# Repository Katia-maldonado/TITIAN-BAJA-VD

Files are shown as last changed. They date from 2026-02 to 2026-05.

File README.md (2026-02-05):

# Baja SAE – Titan Racing Baja
At **CSUF**, our Baja SAE team consists of 14 members, and our goal is to compete in the BAJA SAE Competion that is in Washougal, Washington in May 2026. We are divided into four subteams:

- Chassis / Ergonomics 
- Drivetrain  
- Suspension  
- Vehicle Dynamics / Data Acquisition  

---

## Vehicle Dynamics & Data Acquisition
For the **Vehicle Dynamics / Data Acquisition (VD/DAQ)** subteam, this focuses heavily on the electrical, sensor data, and data analysis work on the car.

We currently run **8 sensors** on the Baja car, all connected to an Arduino based DAQ system to record performance data during testing and competition runs. The system logs:

- Vehicle speed  
- Distance traveled  
- Time  
- Engine RPM  
- Secondary (CVT) RPM  
- Gyroscope data (roll, pitch, yaw)  
- 3-axis acceleration  
- Brake pressure bias  

All sensor data is routed through an **Arduino and SD card reader shield**, allowing each run to be logged directly to an SD card. The recorded data is then processed and analyzed in **MATLAB** to evaluate vehicle performance, CVT behavior, braking balance, and driver inputs.

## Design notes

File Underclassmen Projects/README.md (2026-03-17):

## Coding

I have a few underclassmen projects for anyone interested in writing code for **CVT tuning** and the **main DAQ harness** that will be installed on the car. These projects are a great opportunity to gain hands on experience with Arduino based data acquisition and sensor integration.

For coding related work, please reference **version 8 (v8)** of the code located in the **DAQ** or **version 9 (v9)** in the **CVT** folders. This version should be used as the baseline for development.

If you’re interested, **reach out to Katia on Discord**, and she can answer any questions you may have and help you get started.

---

### CVT DYNO

- [x] Add code to output **live data** onto a screen  
- [x] Display outputs for:
  - [x] Hall effect sensor (Primary RPM)  
  - [x] Hall effect sensor (Secondary RPM)  
  - [x] Hall effect sensor (Disk Brake RPM)  

---

### DAQ (On Vehicle)

- [x] Code the **IMU (MPU-6050)** to record and send its data to the Arduino  
- [x] Log IMU data onto an SD card using the **SD Card Reader Shield** (so it can be exported to Excel / MATLAB later)  
- [x] IMU signals to record:
  - [x] Angular velocity (gyro): **X, Y, Z**
  - [x] Linear acceleration (accelerometer): **X, Y, Z**

> Note: The MPU-6050 is a 3-axis accelerometer and gyroscope. There are many examples available on GitHub and YouTube that can be used as references.

---

### Driver Dash Display

We are also exploring the addition of a **driver dash display** to provide live feedback during vehicle operation. The goal is to give the driver real time readings without relying on post run data analysis.

Planned display outputs include:
- Vehicle speed  
- Secondary RPM  
- CVT belt temperature (IR sensor)  

Due to the off road environment, the display must be **IP67-rated** to withstand dust, water, mud, and vibration. Many off the shelf IP67 displays are expensive, so part of this project is to find **cost effective display solutions** that can meet durability requirements.

This project may include:
- Researching low cost display options compatible with Arduino  
- Designing or selecting a **waterproof enclosure** for the screen  
- Integrating the display with the existing DAQ system  
- Ensuring readability in outdoor and high vibration conditions  

------

## CAD Fixes & Required Updates

The following items outline **specific fixes and updates** that need to be made to the existing CAD drawings for both the **CVT** and **DAQ** electrical harnesses. These updates are necessary to keep the CAD aligned with the actual electrical design and wiring standards.

---

#### CVT Harness CAD (DWG) Fixes

- Fix the electrical connections between the **battery, fuse, buck converter, and GND bus bar**
- Standardize **connector naming**:
  - All identical connectors (ex: all **JST-VH** connectors) should share the same label  
    - Example: all JST-VH connectors labeled as **C3**
- Add a **Quantity** column to the connector table
  - This applies to all repeating connectors
- Rename **BPS** to:
  - **Hall Effect – Brake Wheel RPM**

---

#### DAQ Harness CAD (DWG) Fixes

- Standardize **connector labeling**, following the same rules as the CVT harness
- Add a **Quantity** column to the connector table
- Fix electrical connections between the **battery, fuse, buck converter, and GND bus bar**
- Correct wiring errors where wires were accidentally placed in unused bus bar locations
- Add a **12V bus bar** and move the following components from 5V to **12V**:

**12V Components**
- Spark plug tachometer  
- BPS 1  
- BPS 2  
- Brake switch and brake light (wired in series)  
- Arduino  

**5V Components**
- Hall effect sensor  
- CVT infrared (IR) sensor  
- XBee Xplorer shield  
- IMU  
- GPS  

**GND Connections**
- GPS  
- Push button  
- LED  
- RTC  
- Arduino  
- Spark plug tachometer  
- BPS 1  
- BPS 2  
- Hall effect sensor  
- CVT IR sensor  
- XBee  
- Brake light  
- IMU  
- Buck converter (IN)  
- Buck converter (OUT)  

- **Sheet 3 Fix**:
  - Trim the **GND wire connected to the QWIIC adapter**
  - The wire is currently too long and should be shortened in the DWG

---

Maintaining accurate CAD drawings is critical for harness fabrication, troubleshooting, and future revisions. These fixes should be completed before final harness assembly.

## Sensors - Hands on testing

For those interested in hands on work, there are opportunities to help test and validate the sensors we are using by connecting them to an Arduino and breadboard while we wait for final parts to be delivered. This is a great way to get familiar with the hardware and basic wiring before full integration.

A future project will involve assisting with **harness assembly and integration** once all components arrive, including helping connect and route the wiring for the CVT dyno and on vehicle DAQ systems. Interested students should reach out to Katia for more information.

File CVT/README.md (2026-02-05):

## CVT Dyno Harness & Tuning Overview

In addition to the vehicle DAQ system, we are developing a **separate electrical harness for the CVT dyno**. This setup is designed specifically for **CVT testing and tuning** in a controlled environment and does not require the same level of durability as the on vehicle harness.

The CVT dyno harness uses an **Arduino Uno with an SD card reader shield** to log data and display real time feedback during testing. The system includes the following components:

- Hall effect sensor – Primary RPM  
- Hall effect sensor – Secondary RPM  
- Hall effect sensor – Disk Brake RPM  
- Push button (test control / reset)  
- LED indicators (system status)  
- Real Time Clock (RTC)  
- Display screen for real time output  

The hall effect sensors allow us to measure **primary, secondary, and wheel RPM**, which are critical for understanding CVT behavior under different load and throttle conditions. Data is logged to an SD card for analysis, while the display provides immediate feedback during testing.

---

## Purpose of CVT Tuning

The purpose of CVT tuning is to optimize the transmission’s performance by ensuring the engine operates within its ideal RPM range throughout acceleration and load changes. By analyzing the relationship between **primary RPM, secondary RPM, and wheel RPM**, we can evaluate:

- Shift behavior and ratio changes  
- Belt slip and engagement consistency  
- Backshift response under load  
- Overall drivetrain efficiency  

This data approach allows us to make informed adjustments to **spring rates, flyweights, and CVT setup** rather than relying solely on trial and error. The CVT dyno harness provides a repeatable testing environment that directly supports on vehicle performance improvements.

---

## To Do List

- [x] Hall effect sensor – Primary RPM  
- [x] Hall effect sensor – Secondary RPM  
- [ ] Hall effect sensor – Wheel RPM  
- [x] Push button (test control / reset)  
- [x] LED indicators (system status)  
- [x] Real-Time Clock (RTC)  
- [ ] Display screen for real-time output

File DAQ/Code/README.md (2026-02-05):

## Code Notes & Versioning

**Note:** **Version 8 (v8)** is the most current and stable version of the DAQ code. It has been tested using an **Arduino and breadboard** and should be used as the baseline for any new development.

All new code files must follow the updated naming convention:

Example:
- `v9_DAQ_KM`

---

## Required Code Header Comment

Each DAQ code file must include a **comment block at the very top** of the file describing what the code does and which sensors are used. This helps keep the repository organized and makes code review easier.

### Required Format (Copy & Paste)

```cpp
/*
Version: v#
Author: Name
System: DAQ

Description:
- Brief description of what was added or changed

Sensors Included:
- List all sensors used in this code
*/

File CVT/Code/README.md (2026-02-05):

Note: Version 8 is the most current code and it was tested with an Arduino and Breadboard.

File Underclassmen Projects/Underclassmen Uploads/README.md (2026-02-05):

# Underclassmen Code Submissions

This folder is used for underclassmen to upload **code contributions** related to the **CVT dyno** and **on vehicle DAQ system**. To keep the repository organized and easy to review, please follow the naming and documentation rules below.

---

## File Naming Convention

All uploaded code files must follow this format:

### Examples
- `v9_CVT_KatiaM`
- `v9_DAQ_KatiaM`

### Rules
- Use the current version number (ex: `v9`)
- Specify the system:
  - `CVT` for CVT dyno code
  - `DAQ` for on-vehicle DAQ code
- Use your **first name + last initial**
- Do not use spaces in file names

---

## Required Code Header Comment

Each code file **must include a comment block at the very top** describing what was changed and what sensors are used. This helps with review and future debugging.

### Required Format (Copy & Paste)

```
/*
Author: Your Name
Version: version number (ex:v9)
System: CVT or DAQ

Description:
- Briefly describe what you added or modified in this version

Sensors Included:
- List all sensors used in this code
*/
/*
Author: Katia Maldonado
Version: v9
System: CVT

Description:
- Added live screen output for RPM values
- Improved hall effect sensor debounce

Sensors Included:
- Hall effect sensor (Primary RPM)
- Hall effect sensor (Secondary RPM)
- Hall effect sensor (Wheel RPM)
*/

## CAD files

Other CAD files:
CVT/CAD/v3/CVT_DYNO_V3_BOM_WIRE_CONNECTO_KM.dwg
DAQ/CAD/v6/DAQ_Harness_V6_KM.dwg
DAQ/CAD/v6/DAQ_CONNECTOR_V6_KM.dwg
DAQ/CAD/v6/DAQ_WIRE_V6_KM.dwg
DAQ/CAD/v6/DAQ_Live_Transmission_V6_KM.dwg
DAQ/CAD/v6/DAQ_IMU_ARDUINO_BOX_V6_KM.dwg
DAQ/CAD/v6/DAQ_BOM_V6_KM.dwg
CVT/CAD/v1/CVT_DYNO_V1_KM.dwg
CVT/CAD/v2/CVT_DYNO_V2_KM.dwg
DAQ/CAD/v3/DAQ_Harness_Circuit.dwg
DAQ/CAD/v4/DAQ_V1_KM.dwg
DAQ/CAD/v5/DAQ_Live_Transmission_V1_KM.dwg
CVT/CAD/v2/CVT_DYNO_V2_KM (1).dwg
DAQ/CAD/v4/Live_Transmission_V1_KM.dwg
DAQ/CAD/v5/DAQ_Harness_V1_KM.dwg
DAQ/CAD/v5/DAQ_BOM_V1_KM.dwg
DAQ/CAD/v5/DAQ_IMU_RTC_V1_KM.dwg
DAQ/CAD/v5/DAQ_WIRE_V1_KM.dwg
DAQ/CAD/v5/DAQ_CONNECTOR_V1_KM.dwg

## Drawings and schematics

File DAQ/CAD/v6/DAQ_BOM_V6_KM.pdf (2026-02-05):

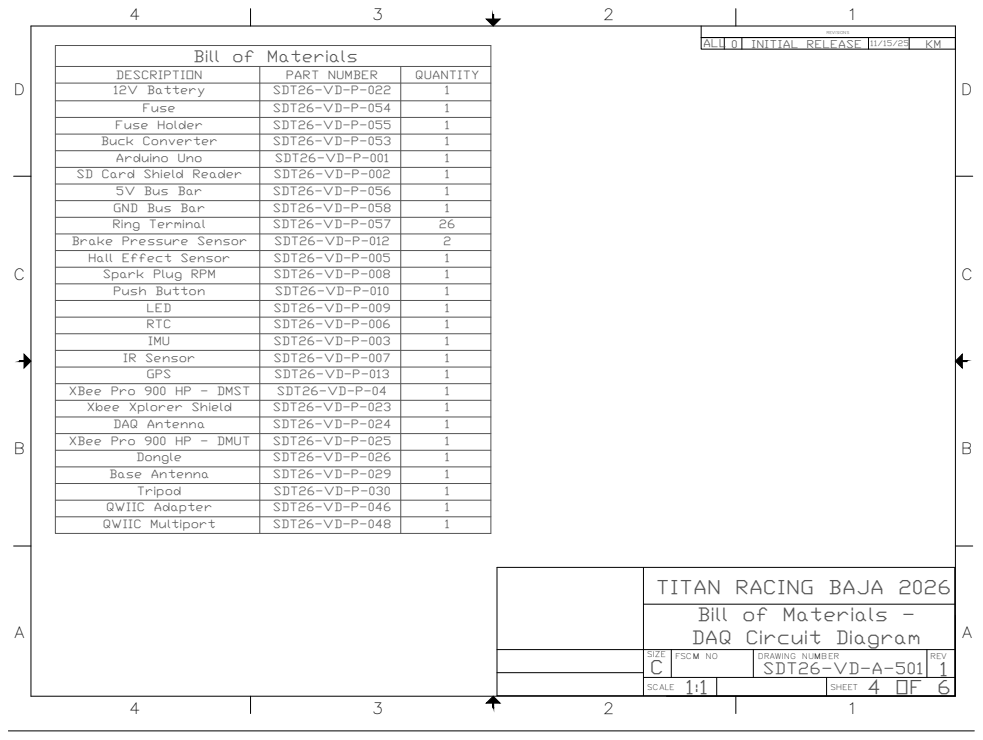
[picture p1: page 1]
D 1 REVISIONS; SIZE; FSCM NO; DRAWING NUMBER; REV SCALE; SHEET Bill of Materials - DAQ Circuit Diagram C; 4 OF 61 ALL 0; INITIAL RELEASE; KM TITAN RACING BAJA 2026 SDT26-VD-A-501 Bill of Materials DESCRIPTION; PART NUMBER; QUANTITY 12V Battery; SDT26-VD-P-022; 1 Fuse; SDT26-VD-P-054; 1 Fuse Holder; SDT26-VD-P-055; 1 Buck Converter; SDT26-VD-P-053; 1 Arduino Uno; SDT26-VD-P-001; 1 SD Card Shield Reader; SDT26-VD-P-002; 1 5V Bus Bar; SDT26-VD-P-056; 1 GND Bus Bar; SDT26-VD-P-058; 1 Ring Terminal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

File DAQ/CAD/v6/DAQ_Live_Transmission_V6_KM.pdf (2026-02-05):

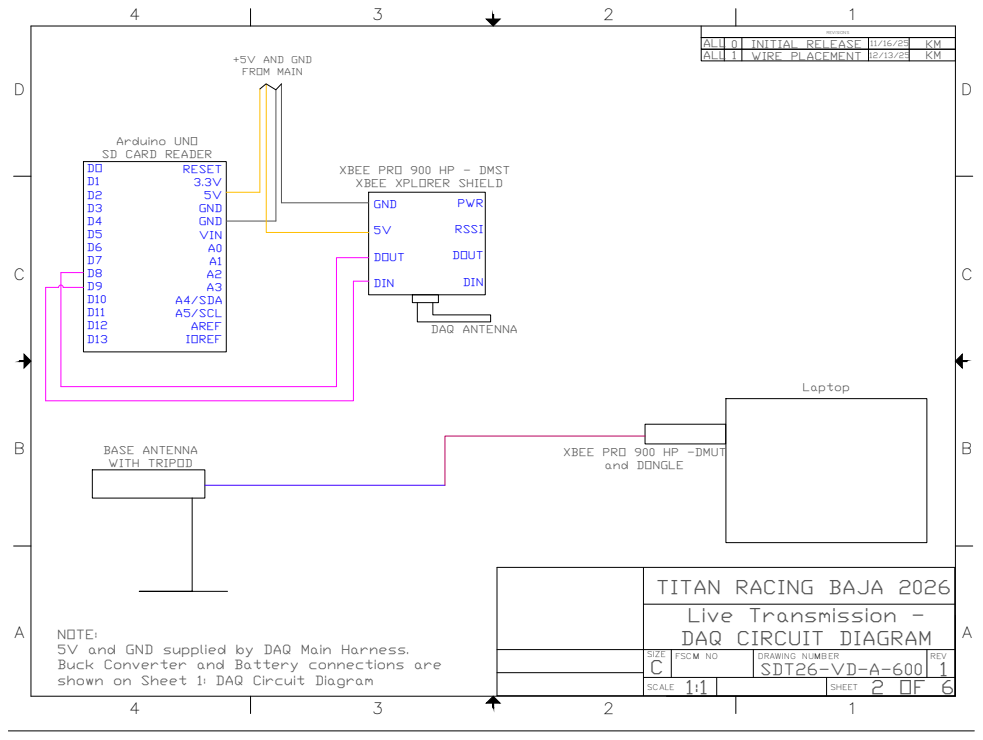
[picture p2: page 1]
D 1 REVISIONS; SIZE; FSCM NO; DRAWING NUMBER; REV SCALE; SHEET Live Transmission - DAQ CIRCUIT DIAGRAM C; 2 OF 61 ALL 0; INITIAL RELEASE; KM TITAN RACING BAJA 2026 SDT26-VD-A-600 DOD1 D2D3D4D5D6D7D8D9D10 D11 D12 D13; RESET 3.3V5V GND GND VINA0A1 A2A3 A4/SDA A5/SCL AREF IOREF Arduino UNO SD CARD READER; +5V AND GND FROM MAIN NOTE: 5V and GND supplied by DAQ Main Harness. Buck Converter and Battery connections are shown on Sheet 1: DAQ Circuit DiagramGND 5VDOUT DIN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

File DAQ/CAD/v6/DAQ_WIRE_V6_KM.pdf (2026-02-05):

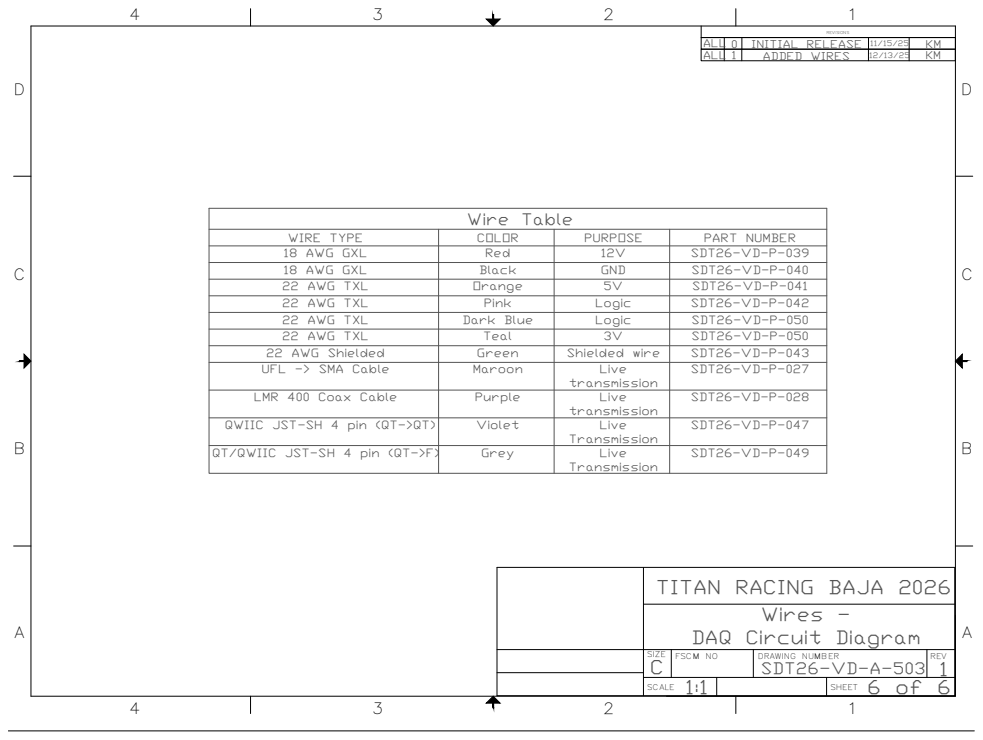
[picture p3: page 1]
D 1 REVISIONS; SIZE; FSCM NO; DRAWING NUMBER; REV SCALE; SHEET Wires - DAQ Circuit Diagram C; 6 of 61 ALL 0; INITIAL RELEASE; KM TITAN RACING BAJA 2026 SDT26-VD-A-503 Wire Table WIRE TYPE; COLOR; PURPOSE; PART NUMBER 18 AWG GXL; Red; SDT26-VD-P-039 18 AWG GXL; Black; GND; SDT26-VD-P-040 22 AWG TXL; Orange; SDT26-VD-P-041 22 AWG TXL; Pink; Logic; SDT26-VD-P-042 22 AWG TXL; Dark Blue; SDT26-VD-P-050 22 AWG TXL; Teal; SDT26-VD-P-050 22 AWG Shielded; Green; Shielded wire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

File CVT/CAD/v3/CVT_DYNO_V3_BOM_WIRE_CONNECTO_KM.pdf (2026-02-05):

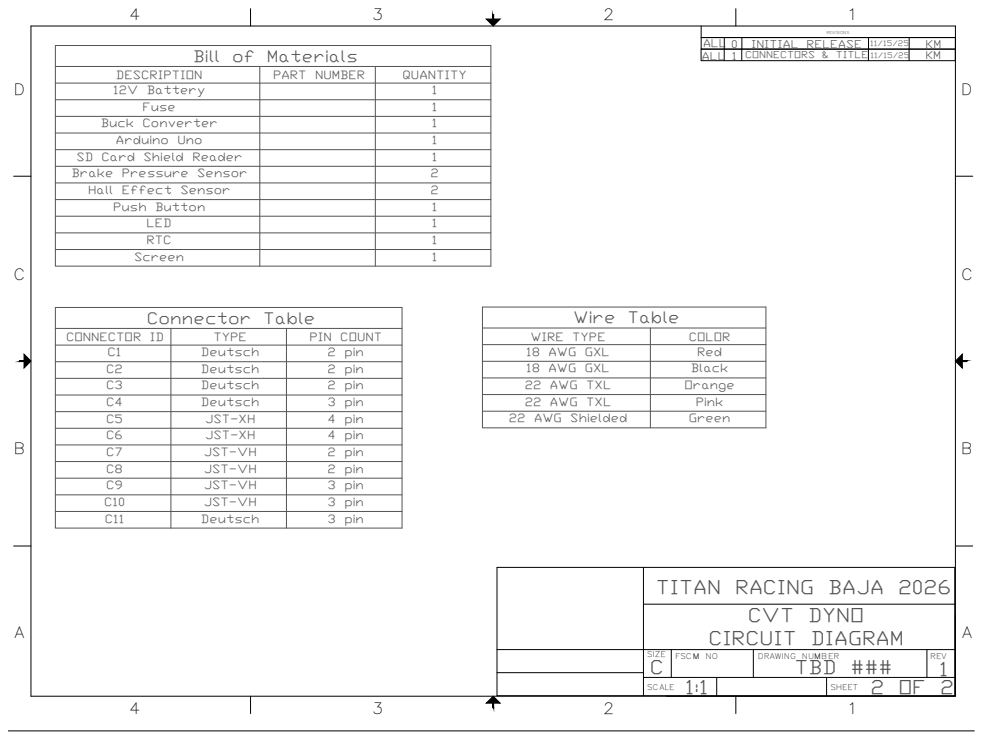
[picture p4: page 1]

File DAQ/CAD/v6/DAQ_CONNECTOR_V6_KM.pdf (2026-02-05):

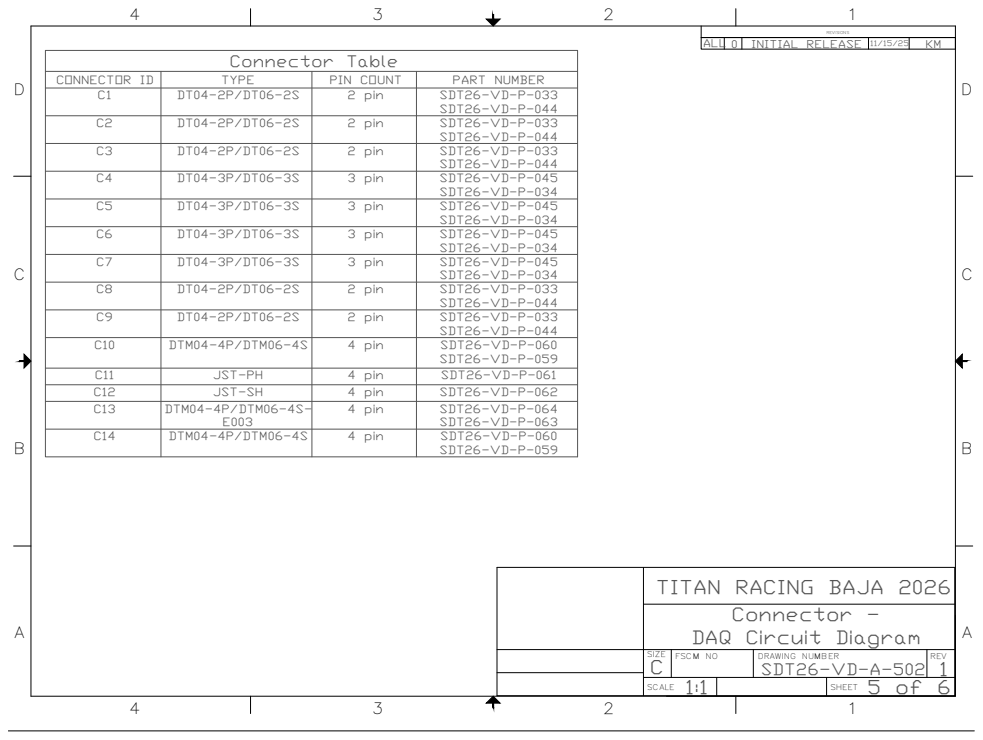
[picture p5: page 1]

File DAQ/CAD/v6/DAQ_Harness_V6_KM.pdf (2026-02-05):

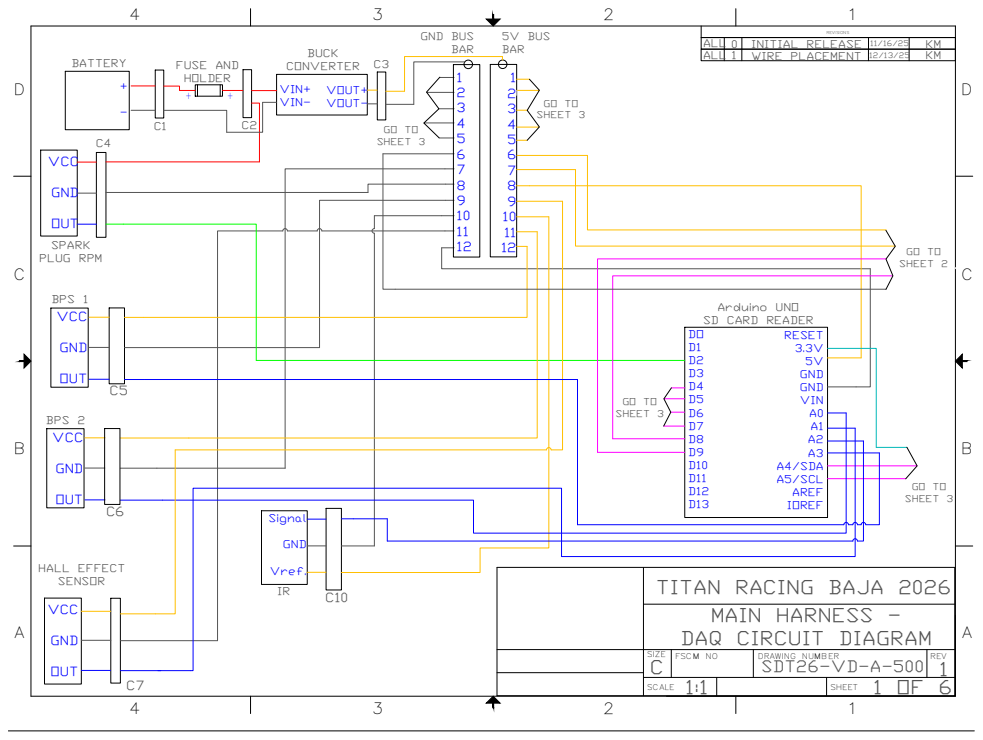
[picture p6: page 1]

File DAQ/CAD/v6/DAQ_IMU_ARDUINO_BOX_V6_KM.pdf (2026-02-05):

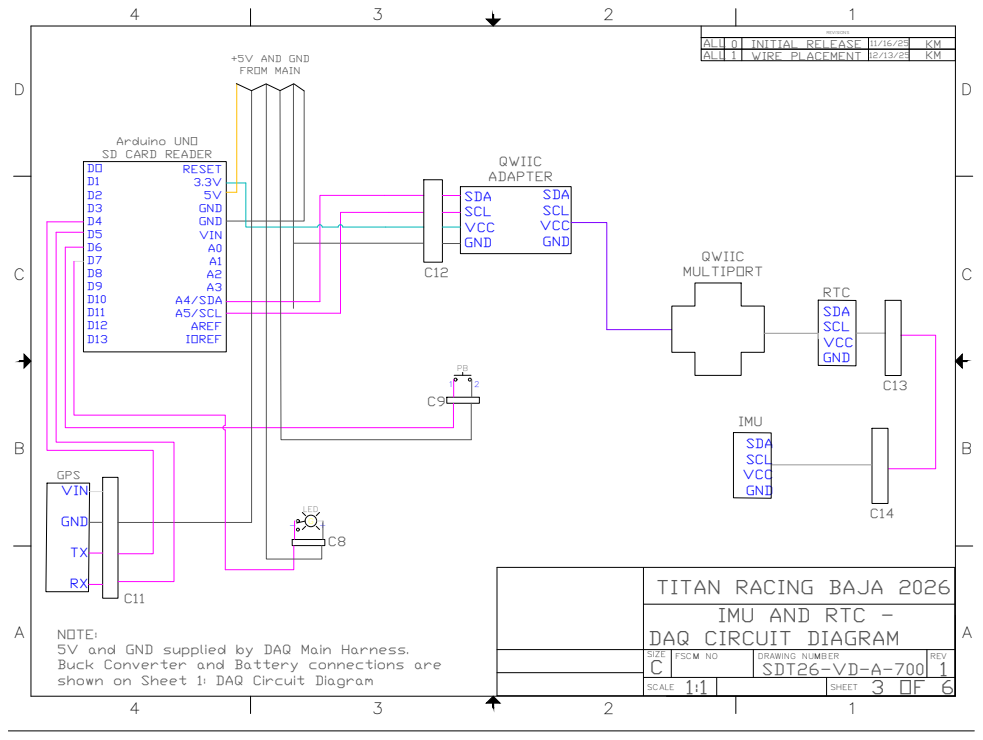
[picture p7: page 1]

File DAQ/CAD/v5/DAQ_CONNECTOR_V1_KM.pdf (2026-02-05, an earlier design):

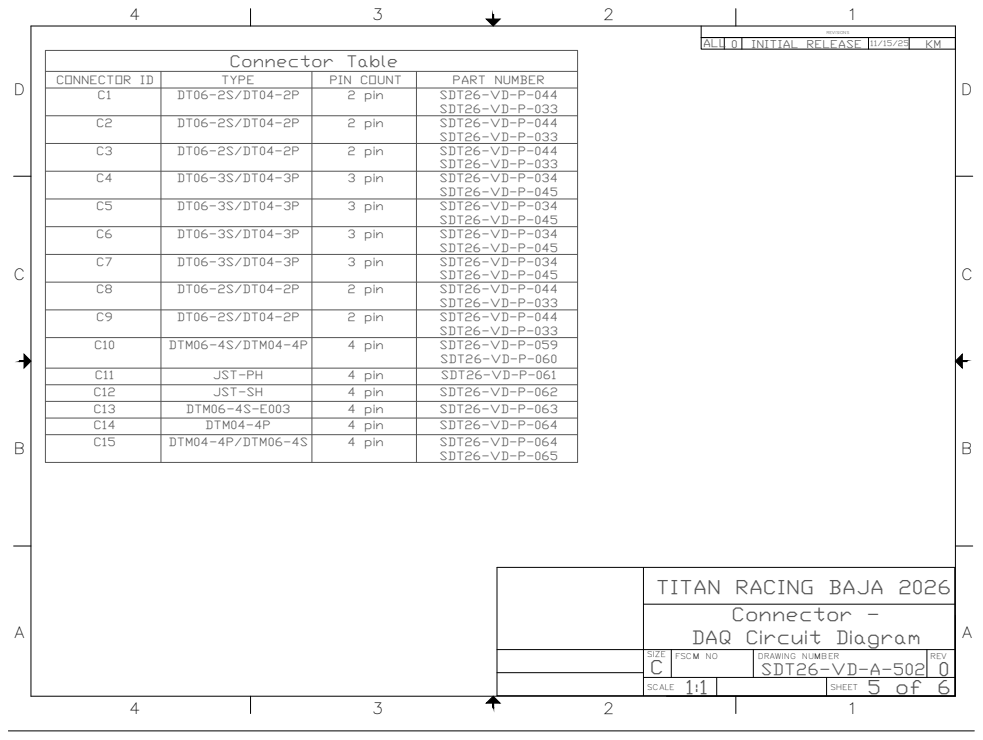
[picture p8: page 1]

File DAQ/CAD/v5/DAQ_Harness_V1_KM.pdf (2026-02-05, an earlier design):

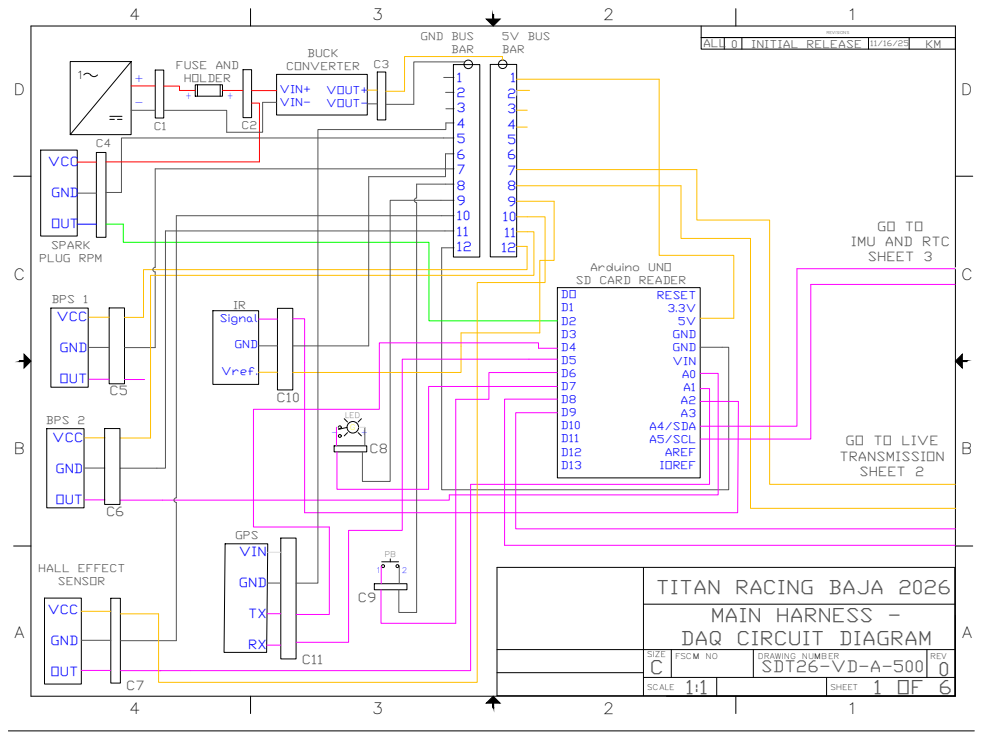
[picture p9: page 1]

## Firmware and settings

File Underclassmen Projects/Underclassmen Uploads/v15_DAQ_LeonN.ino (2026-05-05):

/*
Version: v15
Author: Leon Nguyen
System: DAQ

Description:
- Retained GPS PPS hardware interrupt for silent background tracking, but omitted data from CSV for clean Excel logs [UPDATED]
- Updated IMU software axis mapping to match new physical orientation (X=Up, Y=Left, Z=Rear) [UPDATED]
- Removed DS3231 RTC module dependencies, and shifted entirely to Teensy 4.1 internal hardware RTC (VBAT ON) for zero-latency timestamping [NEW]
- Removed SQW Interrupt hardware sync and Enclosure Temperature tracking [UPDATED]
- Remapped hardware pins across the board, GPS moved to Serial8, XBee moved to Serial5 [UPDATED] 
- IMU address restored to default 0x68 (AD0 pulled low/floating) since it is now the sole device on the bus [UPDATED]
= Removed DIVIDER_MULTIPLIER math for CVT readings [UPDATED]

Sensors Included:
- Spark Plug RPM Adapter (Primary RPM)
- Hall Effect Sensor (Secondary RPM)
- MPU-6050 (Accelerometer & Gyroscope - Interrupt Driven)
- Adafruit Ultimate GPS Module (NMEA 115200 baud, 10Hz, PPS)
- Brake Pressure Sensor (Analog Front)
- Brake Pressure Sensor (Analog Rear)
- CVT Belt Temp Sensor (Analog AiM)
- XBee-PRO 900HP (S3B) (Live-Telemetry Module)

TEENSY 4.1 HARDWARE WIRING GUIDE:
--- COMMUNICATION PINS ---
- IMU(SDA / SCL)         -> Pin 18 / Pin 19
- GPS RX (Serial8 RX8)   -> Pin 34
- GPS TX (Serial8 TX8)   -> Pin 35
- XBee RX (Serial5 RX5)  -> Pin 21
- XBee TX (Serial5 TX5)  -> Pin 20

--- ANALOG PINS ---
- Front Brake Pressure   -> Pin 40 (Shunt Resistor)
- Rear Brake Pressure    -> Pin 41 (Shunt Resistor)
- CVT Belt Temp (AiM IR) -> Pin 38 (5V to 3.3V Divider)

--- DIGITAL PINS ---
- Primary RPM (Spark)    -> Pin 37 (12V to 3.3V Divider)
- Secondary RPM (Hall)   -> Pin 36 (INTERNAL_PULLUP)
- LED Indicator          -> Pin 39 (MOSFET)
- Push Button            -> Pin 23 (INTERNAL_PULLUP)

--- AUXILIARY / SYNC PINS ---
- GPS PPS Pin            -> Pin 33 (Hardware Sync)
- IMU INT Pin            -> Pin 22 (Hardware Sync)
*/

#include <Wire.h>
#include <SPI.h>
#include <SD.h>
#include <TimeLib.h> 
#include <Adafruit_MPU6050.h>
#include <Adafruit_Sensor.h>
#include <TinyGPS++.h>
#include <Watchdog_t4.h>

Adafruit_MPU6050 mpu;
TinyGPSPlus gps;
WDT_T4<WDT1> wdt;

// -------- Pins -------- 
const int pinRPM_Primary   = 37;
const int pinRPM_Secondary = 36;
const int ledPin           = 39;
const int buttonPin        = 23;
const int pinBrakeF        = 40;
const int pinBrakeR        = 41;
const int pinCVT           = 38;
const int pinGPS_PPS       = 33;
const int pinIMU_INT       = 22;

// -------- Settings --------
const unsigned long SAMPLE_MS     = 50;
const uint8_t       PPR           = 2;
const unsigned long DEBOUNCE_MS   = 50; 
const unsigned long RPM_DEBOUNCE  = 2000;

// --- Ring Buffer Settings ---
const int BUFFER_SIZE = 100;
char logBuffer[BUFFER_SIZE][256];
volatile int head = 0;
volatile int tail = 0;
volatile int xbeeTail = 0;

const float DIVIDER_MULTIPLIER = 2.0;
const float MINUTE_MICROS_PPR = 60000000.0 / PPR;

// -------- Counters / State --------
volatile unsigned long lastTimeP = 0;
volatile unsigned long periodP = 0;  

volatile unsigned long lastTimeS = 0;
volatile unsigned long periodS = 0;

volatile unsigned long lastPPSMicros = 0; 
volatile unsigned long ppsDelta = 0; // Tracks microsecond drift

bool logging      = false;
bool lastStable   = HIGH;
bool debouncing   = false;
unsigned long tDebounce = 0;

bool sdOk = false, mpuOk = false;
unsigned long t0_ms = 0; 
char filename[32]; 

File logFile;

// -------- Sensor Data Globals --------
float carAccX = 0, carAccY = 0, carAccZ = 0;
float carGyroX = 0, carGyroY = 0, carGyroZ = 0;

// --- Time Sync Helper Function ---
time_t getTeensy3Time() {
  return Teensy3Clock.get();
}

// --- FASTRUN ISRs (Loaded into ITCM RAM for zero latency) ---
void FASTRUN isrP() { 
  unsigned long now = micros();
  if (now - lastTimeP > RPM_DEBOUNCE) {
    periodP = now - lastTimeP;
    lastTimeP = now;
  }
}

void FASTRUN isrS() { 
  unsigned long now = micros();
  if (now - lastTimeS > 1000) {
    periodS = now - lastTimeS;
    lastTimeS = now;
  }
}

void FASTRUN isrPPS() { 
  unsigned long now = micros();
  ppsDelta = now - lastPPSMicros; // Calculate exact drift
  lastPPSMicros = now; 
}

// -----------------------------------------------------------

void updateGPS() {
  while (Serial8.available() > 0) gps.encode(Serial8.read());
}

void buildNewRunFilename() {
  int run = 1;
  do {
    sprintf(filename, "RUN%03d.CSV", run);
    run++;
  } while (SD.exists(filename));
}

void writeHeader() {
  // PPS columns intentionally omitted to keep CSV clean
  logFile.println(F("Date,Time,P_RPM,S_RPM,AccX,AccY,AccZ,GyroX,GyroY,GyroZ,Lat,Lon,Speed_MPH,BrakeF_PSI,BrakeR_PSI,CVT_TempC"));
  logFile.flush();
  Serial.println(F("Header written"));
}

float readPressurePSI(int pin) {
  int val = analogRead(pin);
  // OPTIMIZED: 12-bit ADC resolution
  float pinVoltage = (val / 4095.0) * 3.3;
  // Calculate raw PSI based on the theoretical 0.60V baseline
  float psi = ((pinVoltage - 0.6) / 2.4) * 2000.0;
  return psi;
}

float readTempC(int pin) {
  // 1. Read the raw 12-bit hardware value (0 to 4095)
  int raw = analogRead(pin);
  
  // 2. Create 'pinV' and calculates the voltage
  float pinV = raw * (3.3 / 4095.0); 
  
  // 3. Now the compiler knows what pinV is
  float sensorV = pinV; 
  
  // 4. Safety check (sensor baseline is 820mV at -20C)
  if (sensorV < 0.8) return -20.0;
  
  // 5. Calculate temp based on the 131.07 °C/V slope
  return (sensorV - 0.82) * 131.07 - 20.0;
}

// --- Custom I2C Burst Read for MPU-6050 ---
void readIMUBurst() {
  Wire.beginTransmission(0x68); // 0x68 is the default MPU address
  Wire.write(0x3B); 
  Wire.endTransmission(false);  // 'false' keeps the I2C connection open/active

  Wire.requestFrom((uint8_t)0x68, (uint8_t)14);
  if (Wire.available() == 14) {
    int16_t rawAccX = Wire.read() << 8 | Wire.read();
    int16_t rawAccY = Wire.read() << 8 | Wire.read();
    int16_t rawAccZ = Wire.read() << 8 | Wire.read();
    int16_t rawTemp = Wire.read() << 8 | Wire.read();
    int16_t rawGyroX = Wire.read() << 8 | Wire.read();
    int16_t rawGyroY = Wire.read() << 8 | Wire.read();
    int16_t rawGyroZ = Wire.read() << 8 | Wire.read();
    
    // --- ORIENTATION MAPPING ---
    // (X points UP, Y points LEFT, Z points REAR)
    // ACCELEROMETER
    carAccX = -(rawAccZ / 4096.0); // Car Forward/Braking (Z is Rear -> Forward is -Z)
    carAccY = -(rawAccY / 4096.0); // Car Cornering Right (Y is Left -> Right is -Y)
    carAccZ =  (rawAccX / 4096.0); // Car Jumps/Vertical Up (X is Up -> Up is +X)
    
    // GYROSCOPE (Right-Hand Rule matched to axes)
    carGyroX = -(rawGyroZ / 65.5); // Roll (Rotation around Forward axis)
    carGyroY = -(rawGyroY / 65.5); // Pitch (Rotation around Right axis)
    carGyroZ =  (rawGyroX / 65.5); // Yaw (Rotation around Up axis)
  }
}

void setup() {
  Serial.begin(9600);
  Wire.begin();
  Wire.setClock(400000);
  Wire.setTimeout(10000);

  static char gpsBuffer[256];
  Serial8.addMemoryForRead(gpsBuffer, sizeof(gpsBuffer));
  static char xbeeBuffer[1024];
  Serial5.addMemoryForWrite(xbeeBuffer, sizeof(xbeeBuffer)); 

  Serial5.begin(115200); 
  
  delay(1000);
  Serial8.begin(9600);
  Serial8.println(F("$PMTK251,115200*1F"));
  delay(100);
  Serial8.begin(115200);
  // "NMEA Diet": Configured to output strictly RMC sentences for reduced CPU load
  Serial8.println(F("$PMTK314,0,1,0,0,0,0,0,0,0,0,0,0,0,0,0,0,0,0,0*29"));
  delay(100);
  Serial8.println(F("$PMTK220,100*2F"));

  pinMode(ledPin, OUTPUT);
  digitalWriteFast(ledPin, LOW);
  pinMode(buttonPin, INPUT_PULLUP);
  pinMode(pinRPM_Primary, INPUT);
  pinMode(pinRPM_Secondary, INPUT_PULLUP);

  pinMode(pinIMU_INT, INPUT); 
  pinMode(pinGPS_PPS, INPUT);
  
  // 12-bit ADC for higher analog sensitivity
  analogReadResolution(12);
  analogReadAveraging(16);

  attachInterrupt(digitalPinToInterrupt(pinRPM_Primary), isrP, RISING);
  attachInterrupt(digitalPinToInterrupt(pinRPM_Secondary), isrS, FALLING);
  attachInterrupt(digitalPinToInterrupt(pinGPS_PPS), isrPPS, RISING);

  wdt.feed();
  sdOk = SD.begin(BUILTIN_SDCARD);

  // --- Teensy Internal RTC Setup ---
  setSyncProvider(getTeensy3Time);
  if (timeStatus() != timeSet) {
    Serial.println(F("Unable to sync with the Teensy RTC"));
  } else {
    Serial.println(F("Teensy RTC has set the system time"));
  }

  // --- IMU Configuration ---
  if (!mpu.begin(0x68)) {
    mpuOk = false;
  } else {
    mpuOk = true;
    mpu.setAccelerometerRange(MPU6050_RANGE_8_G);
    mpu.setGyroRange(MPU6050_RANGE_500_DEG);
    mpu.setFilterBandwidth(MPU6050_BAND_21_HZ);
    
    Wire.beginTransmission(0x68);
    Wire.write(0x37); 
    Wire.write(0x10); 
    Wire.write(0x01); 
    Wire.endTransmission();
  }

  t0_ms = millis();
  WDT_timings_t config;
  config.trigger = 2;
  config.timeout = 3;
  wdt.begin(config);
}

void loop() {
  wdt.feed();
  unsigned long nowMs = millis();
  updateGPS();

  bool raw = digitalReadFast(buttonPin);
  if (!debouncing && raw != lastStable) {
    debouncing = true;
    tDebounce = nowMs;
  }
  
  if (debouncing && (nowMs - tDebounce) > DEBOUNCE_MS) {
    bool raw2 = digitalReadFast(buttonPin);
    if (raw2 != lastStable) {
      if (lastStable == LOW && raw2 == HIGH) {
        if (!logging) {
          wdt.feed();
          if (SD.begin(BUILTIN_SDCARD)) {
            buildNewRunFilename();
            logFile = SD.open(filename, FILE_WRITE);
            if (logFile) { writeHeader(); logging = true; digitalWriteFast(ledPin, HIGH); }
          }
        } else {
          logging = false;
          digitalWriteFast(ledPin, LOW);
          if (logFile) logFile.close();
        }
      }
      lastStable = raw2;
    }
    debouncing = false;
  }

  // --- Main 20Hz Sampling Loop ---
  static unsigned long lastSample = 0;
  if (logging && (nowMs - lastSample >= SAMPLE_MS)) {
    lastSample = nowMs;

    noInterrupts();
    unsigned long pP = periodP; unsigned long tP = lastTimeP;
    unsigned long pS = periodS; unsigned long tS = lastTimeS;
    
    // Track the PPS values in the background in case we need them later
    unsigned long ppsSync = lastPPSMicros; 
    unsigned long syncDelta = ppsDelta; 
    interrupts();
    
    if (mpuOk && digitalReadFast(pinIMU_INT) == HIGH) {
        readIMUBurst();
    }

    float rpmP = (pP > 0 && (micros() - tP < 500000)) ? MINUTE_MICROS_PPR / (float)pP : 0.0;
    float rpmS = (pS > 0 && (micros() - tS < 500000)) ? MINUTE_MICROS_PPR / (float)pS : 0.0;

    if (logFile) {
      static char dataLine[256]; static char timeStr[32];
      time_t t = Teensy3Clock.get(); 
      snprintf(timeStr, sizeof(timeStr), "%04d/%02d/%02d,%02d:%02d:%02d", 
               year(t), month(t), day(t), hour(t), minute(t), second(t));
               
      // Removed PPS values from the string to keep the CSV clean
      snprintf(dataLine, sizeof(dataLine), "%s,%.0f,%.0f,%.2f,%.2f,%.2f,%.2f,%.2f,%.2f,%.6f,%.6f,%.2f,%.0f,%.0f,%.1f", 
               timeStr, rpmP, rpmS, carAccX, carAccY, carAccZ, carGyroX, carGyroY, carGyroZ, gps.location.lat(), gps.location.lng(), gps.speed.mph(), readPressurePSI(pinBrakeF), readPressurePSI(pinBrakeR), readTempC(pinCVT));
               
      int nextHead = (head + 1) % BUFFER_SIZE;
      if (nextHead != tail && nextHead != xbeeTail) {
          strncpy(logBuffer[head], dataLine, 255);
          logBuffer[head][255] = '\0'; head = nextHead;
      } else {
          tail = (tail + 1) % BUFFER_SIZE;
          xbeeTail = (xbeeTail + 1) % BUFFER_SIZE;
          strncpy(logBuffer[head], dataLine, 255); logBuffer[head][255] = '\0'; head = nextHead;
      }
    }
  }
  
  if (!logging) {
      unsigned long blinkInterval = gps.location.isValid() ? 1000 : 200;
      if ((millis() % blinkInterval) < 50) digitalWriteFast(ledPin, HIGH); else digitalWriteFast(ledPin, LOW);
  }
  
  static unsigned long lastForceFlush = 0;
  if (logging && logFile) {
      if (head != tail) { logFile.println(logBuffer[tail]);
      tail = (tail + 1) % BUFFER_SIZE; }
      if (millis() - lastForceFlush > 2000) { logFile.flush();
      lastForceFlush = millis(); }
  }

  if (logging && (head != xbeeTail)) {
      Serial5.println(logBuffer[xbeeTail]);
      xbeeTail = (xbeeTail + 1) % BUFFER_SIZE;
  }
}

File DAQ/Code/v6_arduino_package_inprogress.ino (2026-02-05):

// CSUF BAJA SAE – VD/DAQ (Robust Version)
// Logs even if RTC or IMU init fails.
// Button D7<->GND toggles logging (INPUT_PULLUP). LED D8 ON while logging.
// SD CS=D10. Hall sensors on D2/D3. RTC & IMU share A4(SDA)/A5(SCL). IMU AD0->5V preferred (0x69).

#include <Wire.h>
#include <RTClib.h>
#include <SPI.h>
#include <SD.h>
// #include <Adafruit_MPU6050.h> // <-- REMOVED: Using manual I2C read
// #include <Adafruit_Sensor.h>  // <-- REMOVED: Using manual I2C read

RTC_DS3231 rtc;
// Adafruit_MPU6050 mpu;       // <-- REMOVED: Using manual I2C read

// -------- MPU6050 Manual Read Constants (from working test sketch) --------
const byte MPU_I2C_ADDRESS = 0x69;     // The address your chip is responding to
const byte MPU6050_ID_REG = 0x75;      // WHO_AM_I register
const byte MPU6050_ID_EXPECTED = 0x98; // The ID your specific chip returns
const byte MPU6050_PWR_MGMT_1 = 0x6B;  // Power Management Register
const byte MPU6050_ACCEL_CONFIG = 0x1C; // Accel Config Register
const byte MPU6050_GYRO_CONFIG = 0x1B; // Gyro Config Register
const byte MPU6050_ACCEL_OUT = 0x3B;    // Base register for all sensor data

// Scaling factors for converting raw data to physical units (2g / 250 deg/s ranges)
const float ACCEL_SCALE_FACTOR = 0.000598755; // (2 * 9.80665 / 16384) in m/s^2 per LSB
const float GYRO_SCALE_FACTOR = 0.007633587;  // (250 / 131.0) in deg/s per LSB
// -------------------------------------------------------------------------

// -------- Pins --------
const int SD_CS = 10;
const int hallPrimary = 2;
const int hallSecondary = 3;
const int ledPin = 8;
const int buttonPin = 7;

// -------- Settings --------
const unsigned long SAMPLE_MS = 500;  // use 5000 for hand tests
const uint8_t PPR = 1;                // pulses per rev (magnets per rev)
const unsigned long DEBOUNCE_MS = 50;

volatile unsigned long cntP = 0, cntS = 0;
bool logging = false;
bool lastStable = HIGH, debouncing = false;
unsigned long tDebounce = 0;

bool sdOk = false, rtcOk = false, imuOk = false;
unsigned long t0_ms = 0;  // millis at power-up (fallback time base)
char filename[32];


// --- MPU6050 Manual I2C Functions ---

// Function to manually read one or more registers from the MPU
void readRegisters(byte reg, byte length, byte *data) {
  Wire.beginTransmission(MPU_I2C_ADDRESS);
  Wire.write(reg);
  Wire.endTransmission(false); // Send restart
  Wire.requestFrom(MPU_I2C_ADDRESS, length);
  int i = 0;
  while (Wire.available() && i < length) {
    data[i++] = Wire.read();
  }
}

// Function to write one byte to an MPU register
void writeRegister(byte reg, byte data) {
  Wire.beginTransmission(MPU_I2C_ADDRESS);
  Wire.write(reg);
  Wire.write(data);
  Wire.endTransmission(true);
}

// Custom initialization routine that bypasses the Adafruit ID check
bool initMPU6050() {
  byte chipId = 0x00;
  byte data[1];

  // 1. Check WHO_AM_I ID
  readRegisters(MPU6050_ID_REG, 1, data);
  chipId = data[0];
  Serial.print("MPU WHO_AM_I ID @ 0x69: 0x"); Serial.println(chipId, HEX);

  if (chipId != MPU6050_ID_EXPECTED) {
    Serial.print("ERROR: MPU ID 0x"); Serial.print(chipId, HEX);
    Serial.println(" does not match expected 0x98.");
    return false;
  }

  // 2. Wake up the MPU (clear sleep bit 6, set clock source to PLL with X-axis gyro)
  writeRegister(MPU6050_PWR_MGMT_1, 0x01);

  // 3. Set Gyroscope Configuration (250 deg/s range, bits 4 & 3 are 0)
  writeRegister(MPU6050_GYRO_CONFIG, 0x00);

  // 4. Set Accelerometer Configuration (2g range, bits 4 & 3 are 0)
  writeRegister(MPU6050_ACCEL_CONFIG, 0x00);

  // 5. Success!
  return true;
}


// --- ISRs ---
void isrP() {
  cntP++;
}
void isrS() {
  cntS++;
}

// --- Helpers ---
void buildNewRunFilename() {
  if (rtcOk) {
    DateTime now = rtc.now();
    int run = 1;
    do {
      snprintf(filename, sizeof(filename), "%04d-%02d-%02d_RUN%d.CSV",
               now.year(), now.month(), now.day(), run);
      run++;
    } while (SD.exists(filename));
  } else {
    int run = 1;
    do {
      snprintf(filename, sizeof(filename), "RUN%03d.CSV", run);
      run++;
    } while (SD.exists(filename));
  }
}

void writeHeader() {
  File localFile = SD.open(filename, FILE_WRITE);  // **USE LOCAL FILE HANDLE**
  if (localFile) {
    // NOTE: Header now includes all IMU data (Accel, Gyro)
    if (rtcOk) localFile.println("Date,Time,Primary_RPM,Secondary_RPM,Ax_mps2,Ay_mps2,Az_mps2,Gx_dps,Gy_dps,Gz_dps,Temp_C");
    else localFile.println("Time_s,Primary_RPM,Secondary_RPM,Ax_mps2,Ay_mps2,Az_mps2,Gx_dps,Gy_dps,Gz_dps,Temp_C");
    localFile.close();  // **ALWAYS CLOSE LOCAL HANDLE**
    Serial.println("✅ Header written");
  } else {
    Serial.println("❌ Header write failed (open)");
  }
}

void setup() {
  Serial.begin(9600);
  Wire.begin();

  pinMode(ledPin, OUTPUT);
  digitalWrite(ledPin, LOW);
  pinMode(buttonPin, INPUT_PULLUP);
  pinMode(hallPrimary, INPUT_PULLUP);
  pinMode(hallSecondary, INPUT_PULLUP);
  attachInterrupt(digitalPinToInterrupt(hallPrimary), isrP, FALLING);
  attachInterrupt(digitalPinToInterrupt(hallSecondary), isrS, FALLING);

  Serial.println("Initializing DAQ...");

  // SD first (required for logging)
  sdOk = SD.begin(SD_CS);
  Serial.print("SD: ");
  Serial.println(sdOk ? "OK" : "FAIL");

  // RTC (don’t block if it fails)
  rtcOk = rtc.begin();
  Serial.print("RTC: ");
  Serial.println(rtcOk ? "OK" : "FAIL");
  if (rtcOk && rtc.lostPower()) {
    Serial.println("RTC lostPower -> setting compile time");
    rtc.adjust(DateTime(F(__DATE__), F(__TIME__)));
  }

  // IMU (using manual function)
  Serial.println("--- IMU Initialization ---");
  imuOk = initMPU6050();

  Serial.print("IMU: ");
  Serial.println(imuOk ? "OK" : "FAIL");
  
  // The configuration is now handled within initMPU6050(), 
  // assuming 2g and 250 deg/s ranges.
  // Removed: mpu.setAccelerometerRange(MPU6050_RANGE_8_G);
  // Removed: mpu.setGyroRange(MPU6050_RANGE_500_DEG);
  // Removed: mpu.setFilterBandwidth(MPU6050_BAND_21_HZ);


  t0_ms = millis();
  Serial.println("DAQ ready. Press button to START/STOP logging.");
}
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

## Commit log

2026-02-04 Add DAQ to list of sensors
2026-02-04 Update README to remove unnecessary sections
    Removed sections about VD/DAQ and sensors from README.
2026-02-05 Update README to change Wheel RPM to Disk Brake RPM
2026-02-14 Add files via upload
    GPS code with external antenna attached, correct code to build off of
    [GPS_BPS_DAQ.ino]
